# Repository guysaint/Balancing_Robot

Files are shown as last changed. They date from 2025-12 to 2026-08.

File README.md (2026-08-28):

# Balancing_Robot

STM32F411 과 MPU6050 으로 만든 2륜 밸런싱 로봇. **아직 서지 못합니다.**
중심을 잡으려는 동작까지는 갔고, 진동을 못 잡은 상태에서 취업이 되어 중단했습니다.

2025.12.19 – 12.30 · 커밋 21개

---

## 지금 어디까지 왔나

| | |
|---|---|
| 센서 각도 읽기 | 된다 — 상보필터로 가속도와 자이로를 합쳐 100 Hz 로 |
| 모터 구동·방향 | 된다 |
| 기울면 반응하기 | **된다** — 넘어지는 쪽을 스스로 받치려고 움직인다 |
| 서 있기 | **안 된다** — 떨림이 심해 중심을 잡기 전에 넘어진다 |

마지막 커밋 메시지가 그대로 상태입니다 — *"튜닝중... 여전히 떨림이 너무 심함."*

---

## 구성

| | |
|---|---|
| MCU | STM32F411RE · STM32CubeIDE (HAL) |
| 센서 | MPU6050 — I2C1 (PB8/PB9, Fast) |
| 모터 PWM | TIM2 CH1·CH2 · Period 4999 |
| 모터 방향 | GPIO PC0·PC1 (좌) / PC2·PC3 (우) |
| 디버그 출력 | USART2 로 `printf` |

---

## 제어 구조

**100 Hz 루프** (`HAL_GetTick` 으로 10 ms 마다).

**각도** — 가속도만 쓰면 흔들림에 튀고, 자이로만 쓰면 시간이 갈수록 밀립니다.
그래서 상보필터로 섞습니다.

```c
Acc_Angle     = atan2f(Acc_X_Raw, Acc_Z_Raw) * 57.296f;
Gyro_Rate     = -Gyro_Y_Raw / 131.0f;
Current_Angle = 0.96f * (Current_Angle + Gyro_Rate * Loop_Time)
              + 0.04f * Acc_Angle;
```

MPU6050 의 DLPF 는 `0x03` 으로 두어 약 42 Hz 이상 진동을 센서 단에서 걸러냅니다.

**PID** — 지금 값은 `Kp 380 · Ki 0 · Kd 12`, 목표각 `-2.0°`(수직일 때의 센서 오차).
`Ki` 가 0 이라 실제로는 PD 제어입니다. 누적 제한(±2000)과 리셋 코드는 넣어 뒀습니다.

**안전장치** — 40° 넘게 기울면 모터를 끄고 적분항을 0 으로 되돌립니다.
넘어져 있는 동안 오차가 계속 쌓여 다시 세울 때 튀는 것을 막으려고 넣었습니다.
튜닝을 반복하려면 이게 있어야 편했습니다.

---

## 튜닝하면서 찾은 것

**1. 바퀴가 넘어지는 쪽으로 돌고 있었다**
기울이면 받쳐야 하는데 오히려 넘어지는 방향으로 굴렀습니다. 모터 회전 방향을 뒤집어 고쳤습니다.

**2. 자이로 부호가 반대였다** ← 여기가 제일 오래 걸렸습니다
방향을 고친 뒤에도 못 섰습니다. PID 계산식에 음수를 넣어 봤더니 서는 듯한 모습이 나왔는데,
계산식을 뒤집어서 되는 거라면 **입력 어딘가의 부호가 반대**라는 뜻이었습니다.
모터 방향을 다시 테스트해 보니 모터는 맞았고, 남은 건 센서였습니다.
자이로 각속도에 음수를 붙이니(`-Gyro_Y_Raw`) 그때부터 중심을 잡으려는 동작이 나왔습니다.

**3. 모터에 데드존이 있다**
PWM 을 조금 주면 바퀴가 아예 안 굴렀습니다. 값을 올려가며 재보니 **300 근처에서** 움직이기
시작했고, 여유를 둬서 **750** 을 항상 더해 주도록 했습니다.
PID 출력이 작을 때 아무 일도 일어나지 않는 구간을 없애려는 것입니다.

---

## 남은 문제 — 떨림

서지 못하는 이유는 **떨림**입니다. 중심 근처에서 앞뒤로 크게 흔들리다 넘어집니다.
실물로 확인하지는 못했고, **아래는 코드에서 짚이는 것이지 검증한 것이 아닙니다.**

**가장 의심스러운 것은 데드존 750 입니다.** 지금 값으로 계산해 보면 이렇습니다.

| 기울기 오차 | 모터에 나가는 값 | 듀티 (최대 4999) |
|---|---|---|
| 0° | 0 | 0 % |
| **0.1°** | 38 + 750 = **788** | **15.8 %** |
| 1° | 380 + 750 = 1130 | 22.6 % |

오차가 0 을 지나는 순간 출력이 0 에서 ±788 로 튑니다. 거의 수직인 0.1° 에서도 바퀴에
16 % 를 때리니, 반대로 넘어갔다가 또 튀는 것을 반복하게 됩니다.
**직접 재서 300 에서 움직인다고 확인해 놓고 750 을 쓴 것**이 과합니다.
데드존 보상 자체는 필요하지만, 이만큼 크면 진동을 만드는 쪽으로 작용합니다.

그 다음으로 짚이는 것 둘:

- **Kp 380 이 높고 Kd 12 가 낮다.** 되미는 힘은 센데 그걸 눌러 줄 항이 약합니다
- **자이로 드리프트를 안 잡았다.** 목표각 `-2.0°` 를 손으로 맞춰 넣었고, 시동 시
  캘리브레이션이 없습니다

---

## 다음에 한다면

**1. 데드존부터 되돌린다.** 750 을 측정값에 가깝게(350 안팎) 내리고, 0 근처에서 출력이
급히 튀지 않도록 완만하게 넘어가게 합니다. 위 계산이 맞다면 여기서 제일 크게 달라집니다.

**2. Kd 를 올리고 Kp 를 내려 다시 잡는다.** 데드존을 고친 다음에 해야 의미가 있습니다.
지금은 데드존이 만드는 진동과 게인이 만드는 진동이 섞여 있어서 무엇을 고쳐서 나아졌는지
알 수가 없습니다.

**3. 시동 시 자이로 영점을 자동으로 잡는다.** 지금은 목표각이 코드에 박혀 있습니다.

**4. 서고 난 다음에 엔코더를 붙인다.** TIM3·TIM4 에 엔코더 모드로 설정만 해두고
제어 루프에서는 읽지 않습니다. 엔코더는 **서게 만드는 것이 아니라, 서 있는 로봇이
제자리를 지키게 하는 것**입니다 — 각도만 보면 넘어지지는 않아도 앞으로 스르르 밀려갑니다.
그래서 각도로 서는 것이 먼저이고, 위치 유지가 그 다음입니다.

**5. 그 뒤에 적분항을 켠다.** 남는 기울기 오차를 없애는 단계라 순서상 마지막입니다.

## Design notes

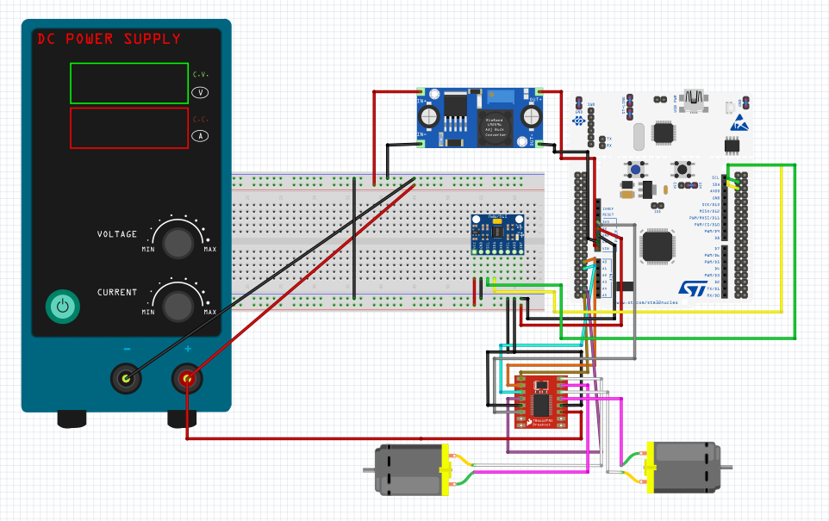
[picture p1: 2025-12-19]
sketch/sketch.png

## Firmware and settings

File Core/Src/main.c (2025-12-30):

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
/* Includes ------------------------------------------------------------------*/
#include "main.h"
#include "i2c.h"
#include "tim.h"
#include "usart.h"
#include "gpio.h"

/* USER CODE BEGIN Includes */
#include <stdio.h>
#include <string.h>
#include <math.h>
#include <stdlib.h>
#define WHO_AM_I_REG 0x75
/* USER CODE END Includes */


/* USER CODE BEGIN PV */
// --- [1. MPU6050 관련 변수] ---
uint8_t MPU6050_ADDR = 0xD0; // (0x68 << 1) or (0x70 << 1) 확인 필요
int16_t Acc_X_Raw, Acc_Z_Raw;
int16_t Gyro_Y_Raw;
float Acc_Angle, Gyro_Rate;
float Current_Angle = 0.0f;
float Loop_Time = 0.01f; // 10ms (100Hz)

// --- [2. PID 제어 변수] ---
// ★ 튜닝할 때 여기 숫자만 바꾸면 됩니다!
float Kp = 380.0f;   // 비례 항 - 힘
float Ki = 0.0f;    // 누적 오차 보정 - 적분
float Kd = 12.0f;    // 급발진 방지(진동을 잡아줌) - 미분

float Target_Angle = -2.0f; // 수직일 때 센서 오차값 (캘리브레이션 값)
float Error, Prev_Error;
float P_Term, I_Term, D_Term;
float PID_Output;

// --- [3. 모터 제어 변수] ---
int Motor_PWM_L, Motor_PWM_R;
/* USER CODE END PV */

void SystemClock_Config(void);
/* USER CODE BEGIN PFP */
void Read_MPU6050(void);
void Motor_Control(int speed_L, int speed_R);
/* USER CODE END PFP */

/* USER CODE BEGIN 0 */
// STM32CubeIDE(GCC)에서 printf 출력을 UART2로 연결
int __io_putchar(int ch) {
    HAL_UART_Transmit(&huart2, (uint8_t *)&ch, 1, 0xFFFF);
    return ch;
}
/* USER CODE END 0 */

/**
  * @brief  The application entry point.
  * @retval int
  */
int main(void)
{

  /* MCU Configuration--------------------------------------------------------*/

  /* Reset of all peripherals, Initializes the Flash interface and the Systick. */
  HAL_Init();

  /* Configure the system clock */
  SystemClock_Config();

  /* Initialize all configured peripherals */
  MX_GPIO_Init();
  MX_USART2_UART_Init();
  MX_I2C1_Init();
  MX_TIM2_Init();
  MX_TIM3_Init();
  MX_TIM4_Init();
  /* USER CODE BEGIN 2 */

    // printf("Balance Robot Start!\r\n");

    // 1. 통신 및 타이머 시작
    HAL_TIM_PWM_Start(&htim2, TIM_CHANNEL_1);
    HAL_TIM_PWM_Start(&htim2, TIM_CHANNEL_2);
    HAL_TIM_Encoder_Start(&htim3, TIM_CHANNEL_ALL);
    HAL_TIM_Encoder_Start(&htim4, TIM_CHANNEL_ALL);

    // 2. MPU6050 깨우기 (Sleep Mode 해제)
    uint8_t data = 0;
    HAL_I2C_Mem_Write(&hi2c1, MPU6050_ADDR, 0x6B, 1, &data, 1, 100);

    //0x1A 레지스터에 0x03을 써서 약 42Hz 이상의 진동 노이즈를 걸러냄.
    uint8_t dlpf_cfg = 0x03;
    HAL_I2C_Mem_Write(&hi2c1, MPU6050_ADDR, 0x1A, 1, &dlpf_cfg, 1, 100);
    //HAL_Delay(100);

  /* USER CODE END 2 */

  /* Infinite loop */
  /* USER CODE BEGIN WHILE */
  while (1)
  {

    /* USER CODE END WHILE */

  /* USER CODE BEGIN 3 */
	  // 데드존을 찾기 위해 pid관련 코드를 주석 처리 함
	uint32_t current_time;
	uint32_t prev_time = 0;

	while (1)
	{
	   current_time = HAL_GetTick();

	  if (current_time - prev_time >= 10) // 10ms 주기 (100Hz)
	  {
		prev_time = current_time;

		// 1. 센서 값 읽기
		Read_MPU6050();

		// ★ [안전장치 추가] 40도 이상 기울어지면 모터 끄기!
		if (Current_Angle > 40.0f || Current_Angle < -40.0f)
		{
			Motor_Control(0, 0); // 모터 정지

			// 넘어져 있을 때는 적분항(I)이 계속 쌓여서 폭발하는 것을 방지하기 위해 초기화
			Error = 0;
			Prev_Error = 0;
			I_Term = 0;
			PID_Output = 0;
		}
		else // 정상 범위(서 있을 때)에만 PID 작동
		{
			// 2. PID 계산
			Error = Target_Angle - Current_Angle;

			P_Term = Kp * Error;
			I_Term += Ki * Error * Loop_Time;
			D_Term = Kd * (Error - Prev_Error) / Loop_Time;

			// I항 누적 제한 (안전용)
			if(I_Term > 2000) I_Term = 2000;
			if(I_Term < -2000) I_Term = -2000;

			Prev_Error = Error;

			// 출력 계산 (부호 확인: 아까 반대로 바꾼 것 유지)
			PID_Output = (P_Term + I_Term + D_Term);
			/*float PID_Total = P_Term + I_Term + D_Term;
			float Min_PWM = 900.0f; // 모터가 '지잉-' 하고 겨우 굴러가는 힘

			// PID 값에 따라 기초 체력을 '살짝' 얹어줍니다.
			if (PID_Total > 0) {
			    PID_Output = PID_Total + Min_PWM;
			}
			else if (PID_Total < 0) {
			    PID_Output = PID_Total - Min_PWM;
			}
			else {
			    PID_Output = 0;
			}*/

			// 3. 모터 제한 및 구동 (풀 파워 해제 버전)
			if (PID_Output > 4700) PID_Output = 4700;
			if (PID_Output < -4700) PID_Output = -4700;

			Motor_Control((int)PID_Output, (int)PID_Output);
		}
		// [디버깅용 코드 추가]
		   //i 변수는 static으로 선언해서 값이 유지되게 함
		//  static int print_count = 0;
		 // if(print_count++ > 20) { // 200ms마다 한 번씩 출력
		//	  printf("Angle: %.2f\r\n", Current_Angle);
		//	  print_count = 0;
		 // }
	  }
	/* ★★★★★ [데드존 찾기 테스트 코드] ★★★★★
		  // 800 -> 1000 -> 1200 -> 1500 -> 1800 ...
		  int test_pwm = 300;

		  // 강제로 모터를 앞으로 돌림.
		  Motor_Control(test_pwm, test_pwm);

		  HAL_Delay(100); // 너무 빠르지 않게 0.1초 대기 */
	}


  /* USER CODE END 3 */
  }
}

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
/* USER CODE BEGIN 4 */
void Read_MPU6050(void) {
	uint8_t buffer[6]; // 데이터 읽기용 버퍼

	// 가속도 읽기 (0x3B: ACCEL_YOUT_H 부터 Z까지) - X, Z축 사용
	HAL_I2C_Mem_Read(&hi2c1, MPU6050_ADDR, 0x3B, 1, buffer, 6, 100);
	Acc_X_Raw = (int16_t)(buffer[0] << 8 | buffer[1]);
	Acc_Z_Raw = (int16_t)(buffer[4] << 8 | buffer[5]);

	// 자이로 읽기 (0x45: GYRO_XOUT_H) - Y축 회전 사용
	HAL_I2C_Mem_Read(&hi2c1, MPU6050_ADDR, 0x45, 1, buffer, 2, 100);
	Gyro_Y_Raw = (int16_t)(buffer[0] << 8 | buffer[1]);

	// 각도 계산 (상보필터)
	// 1. 가속도 각도 (atan2)
	Acc_Angle = atan2f((float)Acc_X_Raw, (float)Acc_Z_Raw) * 57.296f;

	// 2. 자이로 각속도
	Gyro_Rate = -Gyro_Y_Raw / 131.0f;

	// 3. 상보필터 적용 (0.96 : 0.04)
	Current_Angle = 0.96f * (Current_Angle + Gyro_Rate * Loop_Time) + 0.04f * Acc_Angle;
}

void Motor_Control(int speed_L, int speed_R) {
    // 1. 데드존 설정 (300에서 움직였으니, 여유 있게 350으로 설정)
    // 이 값은 "바퀴를 굴리기 위한 최소 통행료"입니다.
    int deadzone = 750;

    // 2. 왼쪽 모터 제어
    if (speed_L > 0) {
        // 전진: 계산된 속도 + 데드존
        speed_L = speed_L + deadzone;

        HAL_GPIO_WritePin(GPIOC, GPIO_PIN_0, GPIO_PIN_SET);   // SET -> RESET
        HAL_GPIO_WritePin(GPIOC, GPIO_PIN_1, GPIO_PIN_RESET); // RESET -> SET
    }
    else if (speed_L < 0) {
        // 후진: 절대값 변환 후 + 데드존
        speed_L = abs(speed_L) + deadzone;

        HAL_GPIO_WritePin(GPIOC, GPIO_PIN_0, GPIO_PIN_RESET);
        HAL_GPIO_WritePin(GPIOC, GPIO_PIN_1, GPIO_PIN_SET);
    }
    else {
        speed_L = 0; // 0이면 정지
        HAL_GPIO_WritePin(GPIOC, GPIO_PIN_0, GPIO_PIN_RESET);
        HAL_GPIO_WritePin(GPIOC, GPIO_PIN_1, GPIO_PIN_RESET);
    }

    // 3. 오른쪽 모터 제어
    if (speed_R > 0) {
        speed_R = speed_R + deadzone;

        HAL_GPIO_WritePin(GPIOC, GPIO_PIN_2, GPIO_PIN_SET);   // IN1
        HAL_GPIO_WritePin(GPIOC, GPIO_PIN_3, GPIO_PIN_RESET); // IN2
    }
    else if (speed_R < 0) {
        speed_R = abs(speed_R) + deadzone;

        HAL_GPIO_WritePin(GPIOC, GPIO_PIN_2, GPIO_PIN_RESET);
        HAL_GPIO_WritePin(GPIOC, GPIO_PIN_3, GPIO_PIN_SET);
    }
    else {
        speed_R = 0;
        HAL_GPIO_WritePin(GPIOC, GPIO_PIN_2, GPIO_PIN_RESET);
        HAL_GPIO_WritePin(GPIOC, GPIO_PIN_3, GPIO_PIN_RESET);
    }

    // 4. 최대 속도 제한 (Period 4999 기준)
    if (speed_L > 4999) speed_L = 4999;
    if (speed_R > 4999) speed_R = 4999;

    // 5. PWM 출력
    __HAL_TIM_SET_COMPARE(&htim2, TIM_CHANNEL_1, speed_L);
    __HAL_TIM_SET_COMPARE(&htim2, TIM_CHANNEL_2, speed_R);
}
/* USER CODE END 4 */
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


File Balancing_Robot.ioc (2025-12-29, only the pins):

Mcu.UserName=STM32F411RETx
PA0-WKUP.Signal=S_TIM2_CH1_ETR
PA1.Signal=S_TIM2_CH2
PA13.GPIO_Label=TMS
PA13.Signal=SYS_JTMS-SWDIO
PA14.GPIO_Label=TCK
PA14.Signal=SYS_JTCK-SWCLK
PA2.GPIO_Label=USART_TX
PA2.Signal=USART2_TX
PA3.GPIO_Label=USART_RX
PA3.Signal=USART2_RX
PA5.GPIO_Label=LD2 [Green Led]
PA5.Signal=GPIO_Output
PA6.Signal=S_TIM3_CH1
PA7.Signal=S_TIM3_CH2
PB3.GPIO_Label=SWO
PB3.Signal=SYS_JTDO-SWO
PB6.Signal=S_TIM4_CH1
PB7.Signal=S_TIM4_CH2
PB8.Signal=I2C1_SCL
PB9.Signal=I2C1_SDA
PC0.GPIO_Label=L_IN1
PC0.Signal=GPIO_Output
PC1.GPIO_Label=L_IN2
PC1.Signal=GPIO_Output
PC13-ANTI_TAMP.GPIO_Label=B1 [Blue PushButton]
PC13-ANTI_TAMP.Signal=GPXTI13
PC14-OSC32_IN.Signal=RCC_OSC32_IN
PC15-OSC32_OUT.Signal=RCC_OSC32_OUT
PC2.GPIO_Label=R_IN1
PC2.Signal=GPIO_Output
PC3.GPIO_Label=R_IN2
PC3.Signal=GPIO_Output

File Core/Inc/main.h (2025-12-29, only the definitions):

#define B1_Pin GPIO_PIN_13
#define B1_GPIO_Port GPIOC
#define L_IN1_Pin GPIO_PIN_0
#define L_IN1_GPIO_Port GPIOC
#define L_IN2_Pin GPIO_PIN_1
#define L_IN2_GPIO_Port GPIOC
#define R_IN1_Pin GPIO_PIN_2
#define R_IN1_GPIO_Port GPIOC
#define R_IN2_Pin GPIO_PIN_3
#define R_IN2_GPIO_Port GPIOC
#define USART_TX_Pin GPIO_PIN_2
#define USART_TX_GPIO_Port GPIOA
#define USART_RX_Pin GPIO_PIN_3
#define USART_RX_GPIO_Port GPIOA
#define LD2_Pin GPIO_PIN_5
#define LD2_GPIO_Port GPIOA
#define TMS_Pin GPIO_PIN_13
#define TMS_GPIO_Port GPIOA
#define TCK_Pin GPIO_PIN_14
#define TCK_GPIO_Port GPIOA
#define SWO_Pin GPIO_PIN_3
#define SWO_GPIO_Port GPIOB

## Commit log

2025-12-23 stm32 보드 + mpu-6050 센서 테스트 코드
2025-12-23 MPU6050 센서의 가속도, 기울기 센서 작동 테스트 코드
2025-12-23 MPU6050 센서의 데이터 값을 Angle값으로 가공함.
    [가속도계]삼각함수로 기울기 계산(atan2 사용)
    [자이로] 각속도를 적분(도/초 -> 도)
    [상보 필터] 가속도(96%)와 자이로(4%)를 섞음.
2025-12-23 mpu6050 센서 영점 캘리브레이션
2025-12-29 밸런싱 로봇 모터 테스트 코드(엔코더 값 확인)
2025-12-29 pid제어 코드 업로드. 튜닝 전. 기울였을 때 모터는 움직이는 것을 확인함
2025-12-29 튜닝 중 모터 속도가 여전히 느려서 밸런스 유지 힘든 수준. kp값과 speed값을 더 올려야 함. 그리고 바퀴가 반대로 돌고 있음 기울이면 넘어지는 방향으로 바퀴가 돌고 있어서 수정해야함
    [main.c]
2025-12-29 모터 회전 방향 정상화. 속도 조절 더 필요함
2025-12-29 속도를 거의 최대로 올림. 그러나 아직 서 있지 못하는 상태.
2025-12-29 40도 기울어지면 모터 끄는 코드 추가(튜닝에 용이하기 위해)
2025-12-29 영점 조정
2025-12-29 튜닝중. 앞뒤로 너무 휙휙 돌아서 중심 잡기도 전에 넘어지고 있음
2025-12-29 튜닝중. 여전히 너무 잘 넘어짐
2025-12-30 계속 튜닝 중.. 로봇이 아직 단 한번도 서 보지 못함
2025-12-30 튜닝중..
2025-12-30 데드존을 찾기 위한 코드 수정
    [main.c]
2025-12-30 pid 계산식에 음수(-)를 넣으니 서는 듯 한 모습이 보여 모터회전 방향이 의심되어 모터 방향 테스트를 진행.
2025-12-30 자이로 센서 방향을 음수(-)로 바꾸니 중심을 잡으려고 시도하는 모습이 보임. 그러나 진동이 심해서 튜닝 필요
2025-12-30 튜닝중... 여전히 떨림이 너무 심함.
2026-08-28 README 추가 — 어디까지 갔고 어디서 멈췄는지
    커밋 로그와 main.c 에서 확인한 것만 적었다. 떨림의 원인으로 데드존 750 을
    지목했는데 이건 계산상의 추정이라 검증한 것이 아니라고 명시했다.
    엔코더는 서게 만드는 것이 아니라 제자리를 지키게 하는 것이라, 다음 단계
    4번에 두었다.

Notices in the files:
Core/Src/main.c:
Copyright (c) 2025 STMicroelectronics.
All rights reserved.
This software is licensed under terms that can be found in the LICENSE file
